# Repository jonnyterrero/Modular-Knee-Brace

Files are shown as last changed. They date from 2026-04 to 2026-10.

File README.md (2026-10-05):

# Modular Knee Brace (MK-Brace)

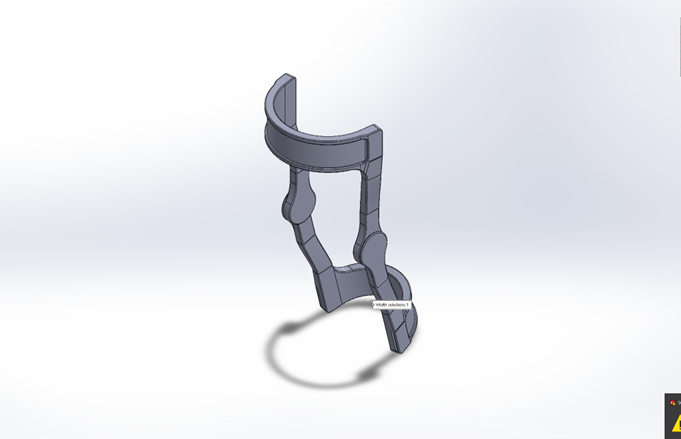
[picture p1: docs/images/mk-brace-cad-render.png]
CAD render of the modular knee brace frame (isometric view)


## Overview
The Modular Knee Brace (MK-Brace) is a lightweight, 3D-printed, parametric rehabilitation device designed to provide joint support, improve comfort, and enable biomechanical data collection.

This project focuses on developing a modular orthopedic system that bridges mechanical design, embedded systems, and rehabilitation engineering.

The current version is a **passive modular brace with planned sensor integration** for motion tracking, load monitoring, and usage analysis.

---

## Objectives

- Reduce bulk and weight compared to traditional braces
- Improve comfort and wearability
- Enable modular customization and repair
- Support a range of leg sizes through parametric CAD
- Provide a platform for biomechanical sensing and data collection
- Maintain low-cost, accessible manufacturing via 3D printing

---

## Key Features

### Mechanical Design
- Modular architecture with interchangeable components
- Mirrored hinge system for bilateral use
- Snap-fit connections with optional secondary fastening
- Parametric sizing for user-specific adjustments
- Designed for rapid prototyping via STL-based workflows

### Materials
- Primary: PLA / PETG (prototype), Nylon (future iterations)
- Structural upgrades: Carbon-fiber-reinforced materials (planned)
- Comfort interface: TPU / soft padding + Velcro straps

### Manufacturing
- Designed in SolidWorks; rebuilt as a parametric Fusion 360 model (2026)
- Exported as STL files (`cad/fusion/stl/`, millimetres)
- Fabricated via FDM 3D printing
- Post-processing includes support removal and adhesive reinforcement

---

## Fusion 360 Model

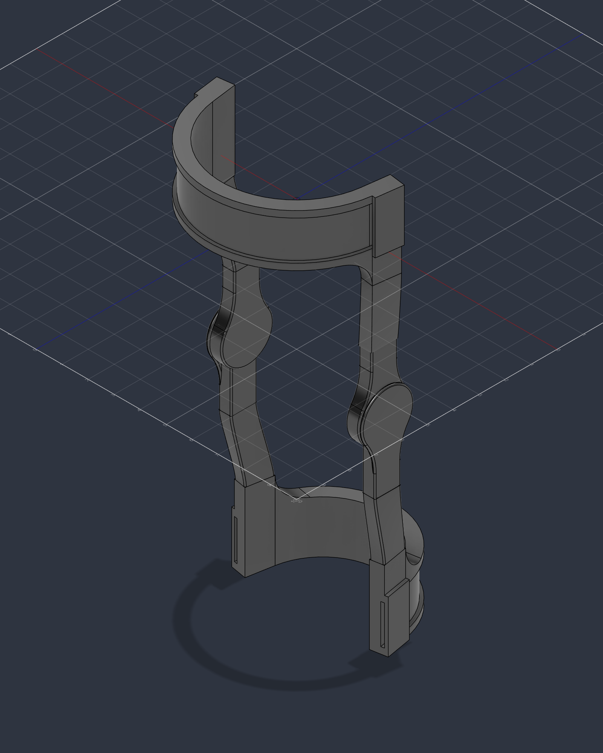
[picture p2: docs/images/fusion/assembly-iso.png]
Fusion 360 assembly of the MK-Brace


The brace was rebuilt in Fusion 360 from the final SolidWorks parts (October 2026):

- **Frames:** native and fully parametric. Thigh and calf fit, wrap angle, socket fit and strap geometry are named parameters.
- **Connectors and hinges:** exact copies of the original SolidWorks parts, positioned around the knee axis.
- **Verified fit** at every joint; corrections to the originals are documented in [`docs/fusion-rebuild.md`](docs/fusion-rebuild.md).

Files, parameters and build scripts: [`cad/fusion/`](cad/fusion/README.md). Current status and next steps: [`HANDOFF.md`](HANDOFF.md).

---

## System Architecture (Planned)

### Mechanical Subsystem
- Hinges (primary load-bearing)
- Connectors (modular joints)
- Upper and lower supports
- Adjustable fastening system

### Embedded System (Future Integration)
- Microcontroller: ESP32
- Sensors:
  - Magnetic rotary encoder (knee angle)
  - Dual IMUs (thigh + shin)
  - Pressure sensors (fit and load monitoring)
- Power: LiPo battery
- Communication: BLE / USB

---

## Use Case

The MK-Brace is designed for:
- Post-injury rehabilitation
- Mild-to-moderate knee instability
- Gait monitoring and movement tracking
- Long-duration wearable support

---

## Development Roadmap

### Phase 1 — Mechanical Prototype
- Finalize CAD geometry
- Print and assemble prototype
- Validate fit, comfort, and structural integrity

### Phase 2 — Instrumentation
- Integrate sensors into brace structure
- Develop mounting and enclosure solutions

### Phase 3 — Firmware
- Sensor acquisition and filtering
- Angle estimation and motion tracking
- Data logging and communication

### Phase 4 — Data & Analysis
- ROM tracking
- Usage analytics
- Gait pattern insights

### Phase 5 — Iteration & Optimization
- Material upgrades
- Custom PCB development
- Improved ergonomics and manufacturability

---

## Current Status
- Mechanical design: Fusion 360 rebuild complete (10-part parametric assembly, fit verified)
- Prototype fabrication: Print files ready in `cad/fusion/stl/`
- Embedded system: Next: sensors, battery and schematics (see `HANDOFF.md`)
- Software stack: Fusion API build and export scripts in `cad/fusion/scripts/`; firmware not started

---

## Repository Structure

| Path | Contents |
| --- | --- |
| `docs/` | Course write-up `EGN-3433C-Design-Project-Final.docx`; images in `images/`; dimensioned drawings and design sketches in `drawings/`; FEA report in `simulation/`; rebuild notes `fusion-rebuild.md`; session logs in `progress/` |
| `cad/` | Top-level release assembly: `finalkneeassem4.SLDASM` |
| `cad/fusion/` | Fusion 360 model: `.f3d` archive, STEP assembly, per-part STLs (mm) and Fusion API scripts |
| `cad/solidworks-final/` | Final SolidWorks parts, assemblies and drawings the Fusion model was rebuilt from |
| `HANDOFF.md`, `AGENTS.md`, `CLAUDE.md` | Current state and next steps; instructions for AI agents |
| `modular-knee-brace-package/` | Complete design hand-off: instruction PDF, SolidWorks assemblies and parts, STL print files, and simulation artifacts (`files/`, including `.CWR` and related solver files) |
| `resources/` | Pointers to external learning repos, [GrabCAD](https://grabcad.com/), and [SolidWorks Python tooling](https://github.com/Glutenberg/swtoolkit) (see `resources/README.md`) |

Large CAD, meshes, and simulation results are stored with **Git LFS**; clone with [Git LFS](https://git-lfs.com/) installed so pointers resolve to real files.

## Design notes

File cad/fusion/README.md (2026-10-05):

# Fusion 360 model

Parametric Fusion 360 rebuild of the MK-Brace (October 2026). The live design is **Modular Knee Brace** in the Fusion project **Knee brace Design**; the files here are exports of it plus the scripts that build it.

Fusion 360 assembly

## Files

| Path | What it is |
| --- | --- |
| `Modular-Knee-Brace.f3d` | Fusion archive with the full timeline, user parameters and all 10 parts (*File → Open → Open from my computer*) |
| `Modular-Knee-Brace.step` | Neutral STEP of the whole assembly in its assembled position |
| `stl/` | One binary STL per part, in **millimetres**, ready to slice |
| `scripts/` | Fusion API scripts that rebuild, measure and export the design |

### Parts and print quantities

| Part | STL | Qty | Source |
| --- | --- | --- | --- |
| Top Frame (thigh) | `top-frame.stl` | 1 | Native parametric (`build_frames`) |
| Bottom Frame (calf) | `bottom-frame.stl` | 1 | Native parametric (`build_frames`) |
| Upper Connector | `left-upper-connector.stl`, `right-upper-connector.stl` | 1 each | Original SolidWorks geometry |
| Lower Connector | `left-lower-connector.stl`, `right-lower-connector.stl` | 1 each | Original SolidWorks geometry |
| Inner Hinge | `left-inner-hinge.stl`, `right-inner-hinge.stl` | 1 each | Original SolidWorks geometry |
| Outer Hinge | `outer-hinge.stl` | **2** | Original SolidWorks geometry |

## Coordinates and units

- Model units are inches. Y is the leg axis (up), Z points to the front, X is lateral.
- The Top Frame is the assembly origin; the knee (hinge) axis is at (0, −6.0, −0.5) in.

## Frame parameters

Change them in *Modify → Change Parameters*; both frames, their sockets, gussets and strap paths follow.

| Parameter | Default | Meaning |
| --- | --- | --- |
| `top_frame_id` | 5.75 in | Top frame bore (thigh fit) |
| `bottom_frame_id` | 4.50 in | Bottom frame bore (calf fit) |
| `top_frame_half_angle` | 82.5° | Half the top frame's wrap |
| `bottom_frame_half_angle` | 80° | Half the bottom frame's wrap (matches the lower connectors' 10° tabs) |
| `frame_height` | 2.00 in | Band height |
| `frame_wall` | 0.50 in | Band thickness |
| `block_length`, `block_drop` | 1.00 in, 1.00 in | End block length; how far it drops toward the knee (also the gusset radius) |
| `tab_width`, `tab_thickness`, `tab_length` | 0.75, 0.25, 1.00 in | Connector tab |
| `fit_clearance` | 0.01 in | Per side, tab to socket |
| `socket_flare_depth` | 0.319 in | Flared socket mouth that seats the tab's R0.5 root |
| `strap_recess_height`, `strap_recess_depth` | 1.50 in, 0.125 in | Strap recess and strap slot |
| `lip_thickness` | 0.125 in | Strap bridge over each end-block slot |

The connectors and hinges are exact copies of the SolidWorks parts, so they do **not** follow these parameters (see [`docs/fusion-rebuild.md`](../../docs/fusion-rebuild.md)).

## Scripts

| Script | Does |
| --- | --- |
| `build_frames` | Creates the parameters and both parametric frames in the active design |
| `place_original_parts` | Copies the original connectors and hinges from *Knee brace Design / SolidWorks originals* and places them around the knee |
| `measure_part` | Prints size, volume, cylinder diameters and planar-face offsets of every body |
| `export_brace` | Writes the `.f3d`, `.step`, `stl/` and the `docs/images/fusion/` renders back into this repo |

Run one from Fusion: *Utilities → Add-Ins → Scripts and Add-Ins → + (Script) → select its folder → Run*.

Rebuild from scratch: new design → `build_frames` → `place_original_parts`. On 2026-10-04 this reproduced the saved design exactly (all 10 parts, volume and bounding box).

From Claude Code with the Fusion MCP connected, run a repo script by loading the file, so the committed code is what runs:

```python
import importlib.util

def run(_context: str):
    path = r'<repo>\cad\fusion\scripts\build_frames\build_frames.py'
    spec = importlib.util.spec_from_file_location('build_frames', path)
    module = importlib.util.module_from_spec(spec)
    spec.loader.exec_module(module)
    module.run('')
```

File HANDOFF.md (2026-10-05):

# Handoff — where the MK-Brace work stands

_Last updated 2026-10-04 by Claude Code (Opus 5.5). Full session log: [`docs/progress/2026-10-04-fusion-rebuild.md`](docs/progress/2026-10-04-fusion-rebuild.md)._

Read this first when picking the project back up, and update it at the end of every session.

## Current state

- **Phase 1 (mechanical): Fusion rebuild done.** The brace is a 10-part Fusion 360 assembly: two parametric frames plus exact copies of the original connectors and hinges, with fit checked at every joint.
- **Fusion cloud:** project **Knee brace Design** holds the design **Modular Knee Brace** (v2) and the folder **SolidWorks originals** (the 9 converted reference parts). Save new Fusion work in this project, never in *Default Project*.
- **Repo:** exports and scripts in [`cad/fusion/`](cad/fusion/README.md); engineering notes in [`docs/fusion-rebuild.md`](docs/fusion-rebuild.md); the reference SolidWorks set in [`cad/solidworks-final/`](cad/solidworks-final/); drawings in [`docs/drawings/`](docs/drawings/).
- **Print-ready:** `cad/fusion/stl/` (millimetres). Print the Outer Hinge twice.

## Next up (week of 2026-10-05): electronics

The README's Phase 2/3 plan: ESP32, a magnetic rotary encoder at the hinge (knee angle), dual IMUs (thigh + shin), pressure sensors (fit and load), a LiPo battery, BLE/USB.

1. Choose parts and write a power budget (target runtime → battery capacity).
2. Draw the schematics in KiCad (an MCP server is configured on the dev machine) or Fusion Electronics, under a new `electronics/` folder.
3. Design the mounts in Fusion. The report puts add-ons at the hinges first, so start with the encoder on the hinge axis and an enclosure for the MCU and battery.
4. Update this file, add a `docs/progress/` entry, and commit to `main`.

Open questions:

- Is electrical-stimulation (e-stim) therapy in scope? The report mentions an e-stim battery pack. Anything patient-connected is safety-critical: keep it a separate, isolated module and decide before designing the power system.
- Target runtime per charge, and where the battery and MCU should sit (thigh frame or hinge).
- Material for the first printed prototype (README: PLA/PETG now, nylon or carbon fibre later).

## Resume on the desktop

1. Pull this repo (Git LFS required) and open it in Claude Code.
2. Start Fusion. Its MCP server must be on port **47182** (Preferences → General → API); [`AGENTS.md`](AGENTS.md#fusion-360-via-mcp) explains why.
3. Open **Knee brace Design / Modular Knee Brace** and confirm the Fusion tools respond.

## Known issues

- The frames lack the originals' small edge rounds and end-block draft (cosmetic).
- Connectors and hinges don't follow the frame parameters (copied geometry).
- About 0.003 in press fit on one side of each hinge seat, inherited from the originals.

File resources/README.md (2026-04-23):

# Resources

Curated external links for SolidWorks learning, example files, community CAD, and API automation. These are not part of the MK-Brace project; they are reference material for contributors and future design work.

## Training & exercise repositories

| Resource | Link | Notes |
| --- | --- | --- |
| *SOLIDWORKS 2016 Essential Training* (Tertiary Infotech) — exercise files | [tertiarycourses/SolidworksTraining](https://github.com/tertiarycourses/SolidworksTraining) | Official course materials for a structured essentials curriculum; [course outline](https://www.tertiarycourses.com.sg/solidworks-2016-essential-training.html) is listed in that repo. |
| *Learn SOLIDWORKS* (second edition, Packt) — chapter project files | [PacktPublishing/Learn-SOLIDWORKS-Second-Edition](https://github.com/PacktPublishing/Learn-SOLIDWORKS-Second-Edition) | Book companion assets organized by chapter; see the book README for the intended software and chapter mapping. |

## SolidWorks + Python (API automation)

| Resource | Link | Notes |
| --- | --- | --- |
| SW ToolKit | [Glutenberg/swtoolkit](https://github.com/Glutenberg/swtoolkit) | Python toolkit to script SolidWorks (batch exports, build automation, etc.). **Requires** a local SolidWorks install and a Windows environment suitable for the COM API. |

## Community CAD

| Resource | Link | Notes |
| --- | --- | --- |
| GrabCAD | [grabcad.com](https://grabcad.com/) | Public library of user-uploaded models; useful for reference geometry, fastener/standard parts, and design inspiration. Check each model’s **license and terms of use** before reusing. |

---

## Disclaimer

Repository contents and licenses are defined by their respective owners. Verify compatibility with your **SolidWorks version** before opening third-party files.

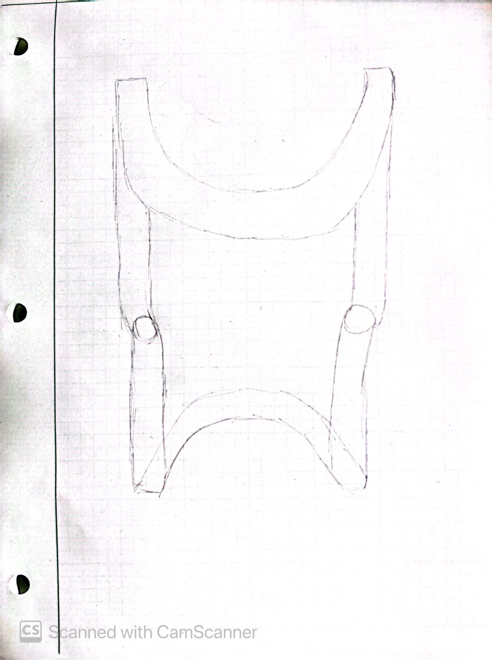
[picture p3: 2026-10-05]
docs/drawings/sketch-concept.jpg

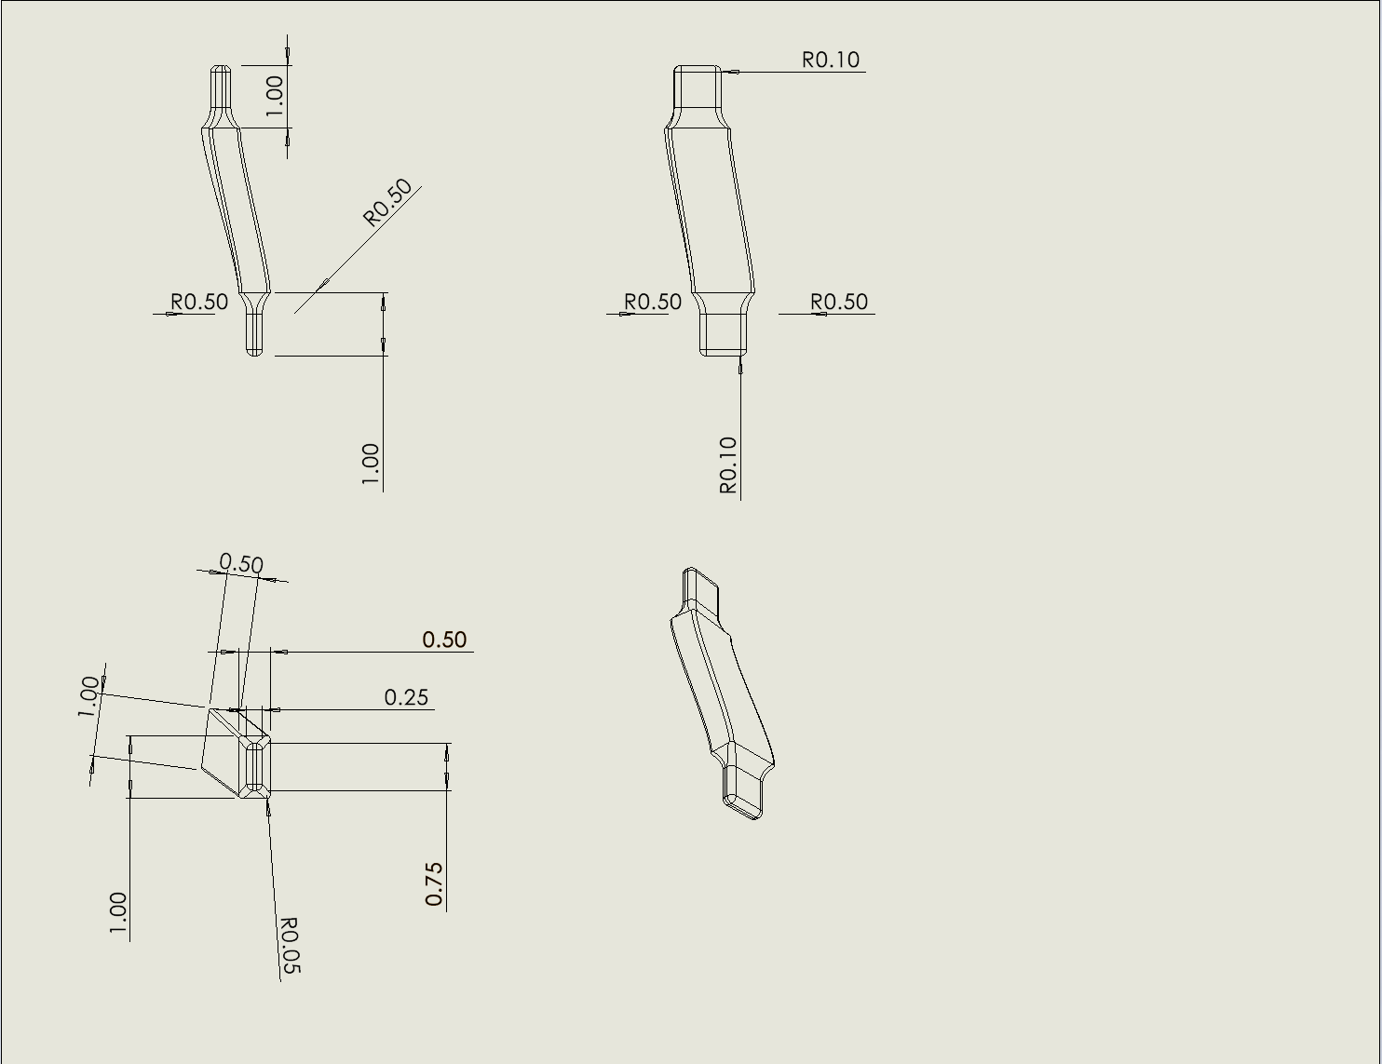
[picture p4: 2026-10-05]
docs/drawings/drawing-3-upper-connector.png

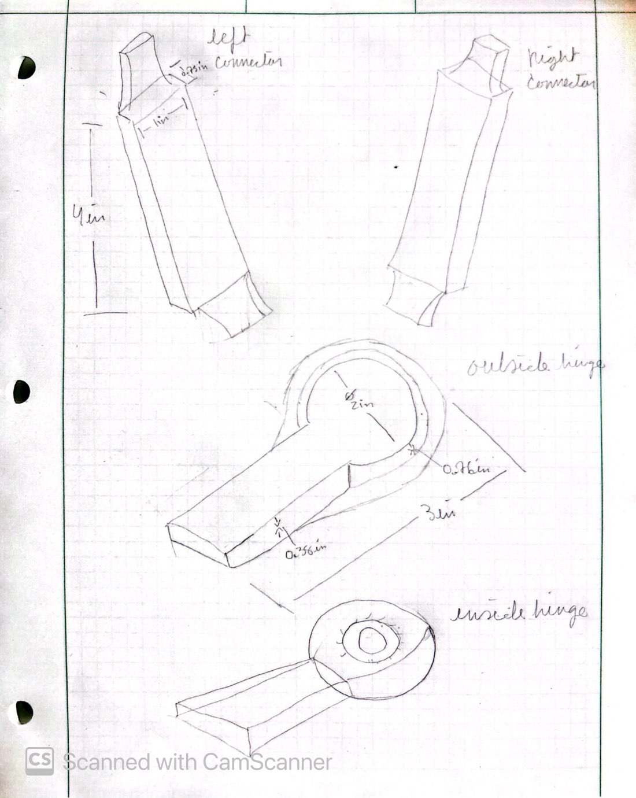
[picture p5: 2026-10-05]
docs/drawings/sketch-connectors-and-hinges.jpg

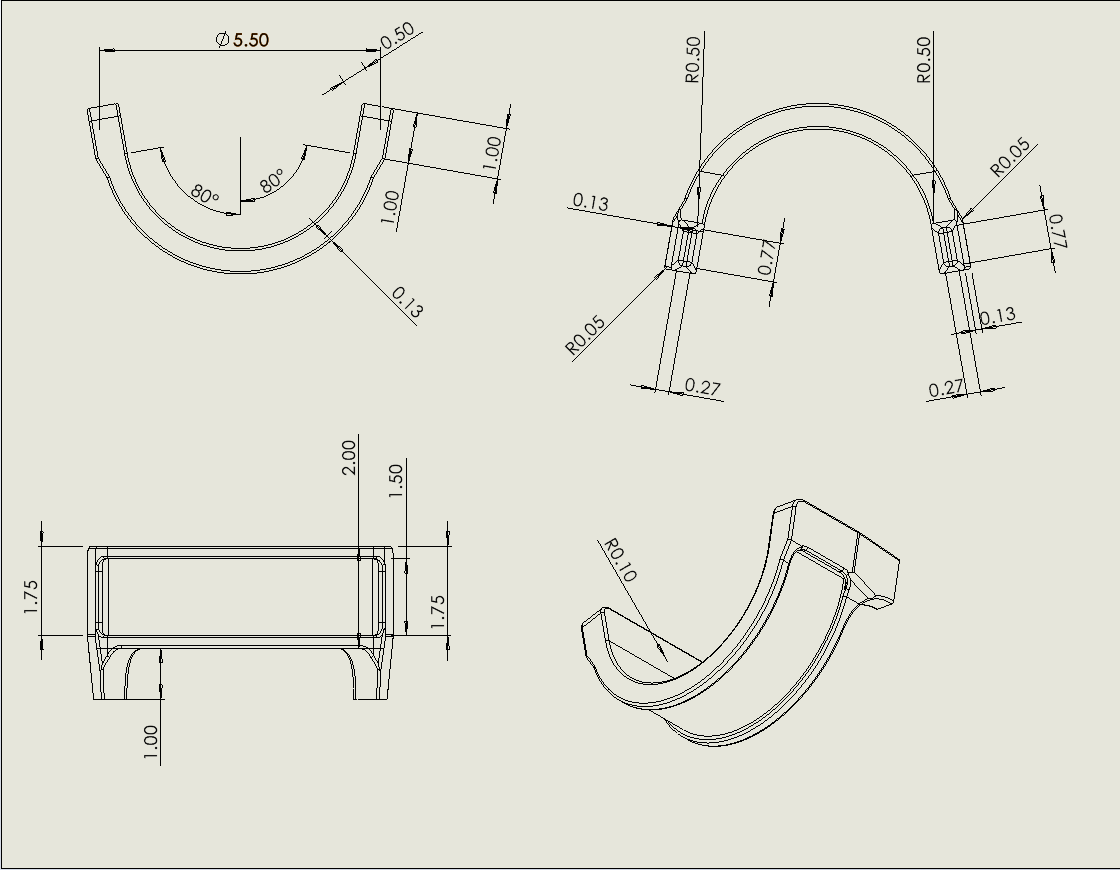
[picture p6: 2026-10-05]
docs/drawings/drawing-2-bottom-frame.png

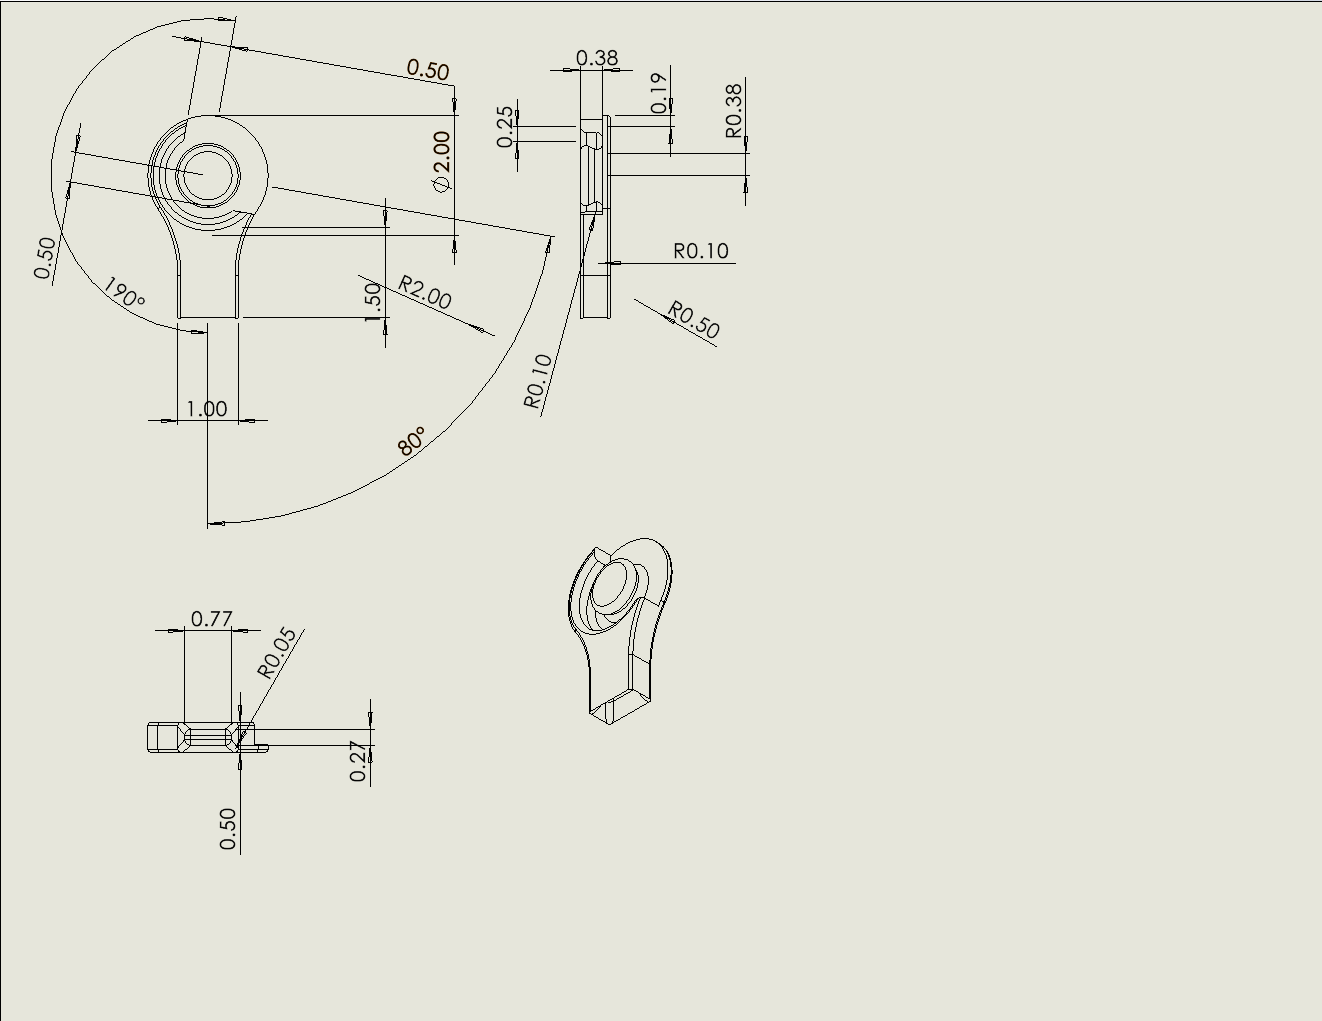
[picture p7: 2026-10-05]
docs/drawings/drawing-6-inner-hinge.png

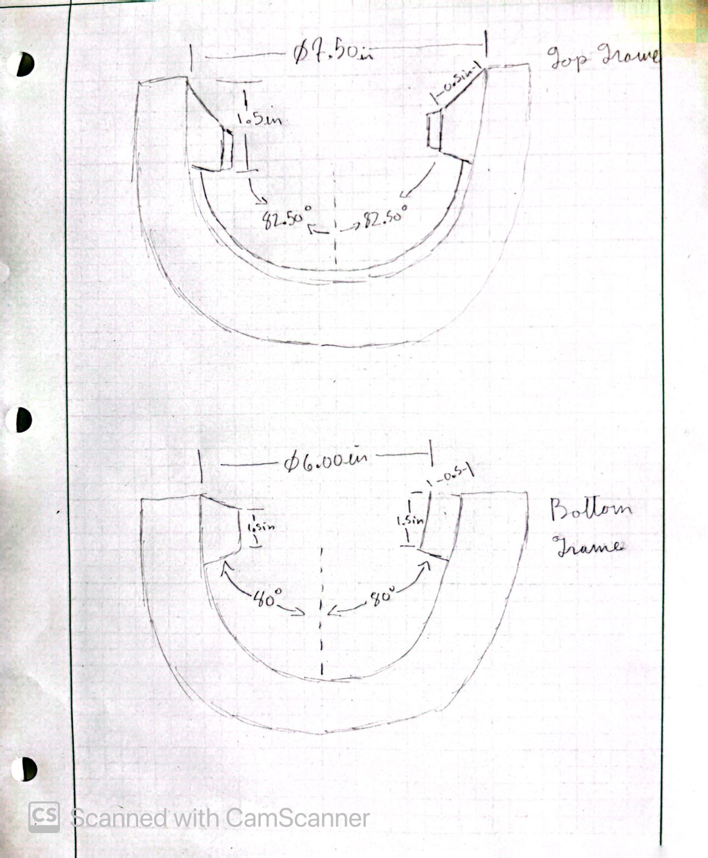
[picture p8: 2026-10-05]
docs/drawings/sketch-frames.jpg

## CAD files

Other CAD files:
cad/finalkneeassem4.SLDASM
cad/solidworks-final/Final_Final_Assembly.SLDASM
modular-knee-brace-package/files/Left_Hinge.SLDASM
cad/solidworks-final/hingeassembly.SLDASM
modular-knee-brace-package/files/Assem1.SLDASM
modular-knee-brace-package/files/FINAL_BRACE_ASSEMBLY.SLDASM
modular-knee-brace-package/files/Right_Hinge.SLDASM
modular-knee-brace-package/files/Assem2.SLDASM
cad/fusion/Modular-Knee-Brace.step
cad/fusion/stl/right-upper-connector.stl
cad/solidworks-final/Hinge_Outerfinal.SLDPRT
modular-knee-brace-package/files/Left_Lower_Connectorfinal.SLDPRT
cad/fusion/stl/left-upper-connector.stl
cad/solidworks-final/Left_Hinge_Innerfinal.SLDPRT
modular-knee-brace-package/files/Left_Lower_Connector.STL
cad/fusion/stl/right-inner-hinge.stl
cad/solidworks-final/Right_Upper_Connectorfinal.SLDPRT
modular-knee-brace-package/files/Lower.SLDPRT
cad/fusion/Modular-Knee-Brace.f3d
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

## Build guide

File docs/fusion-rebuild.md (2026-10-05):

# Fusion 360 rebuild — engineering notes

How the SolidWorks MK-Brace became the parametric Fusion model in [`cad/fusion/`](../cad/fusion/README.md), what was measured, and what was corrected. Session log: [`progress/2026-10-04-fusion-rebuild.md`](progress/2026-10-04-fusion-rebuild.md).

## Source of truth

The rebuild follows the final SolidWorks set in [`cad/solidworks-final/`](../cad/solidworks-final/). Those `…final` parts were saved on 2025-05-02, the day the final report was saved, after every iteration in the course working folder (`pt2`, `pt3`, `Mirror…`). They differ from the parts in `modular-knee-brace-package/`.

The parts were uploaded to Fusion (project *Knee brace Design*, folder *SolidWorks originals*), converted, and measured face by face with `measure_part`.

## Measured geometry

### Frames (one design, two sizes)

| | Top Frame (thigh) | Bottom Frame (calf) |
| --- | --- | --- |
| Bore / outside diameter | 5.75 / 6.75 in | 4.50 / 5.50 in |
| Wrap (2 × half-angle) | 165° | 160° (see corrections) |
| Band height × wall | 2.00 × 0.50 in | 2.00 × 0.50 in |
| End blocks | 1.00 in tangent extension; drop 1.00 in toward the knee | same |
| Socket | 0.77 × 0.27 in, 1.01 in deep, R0.5 flared mouth over 0.319 in | same |
| Strap path | 1.50 × 0.125 in recess on the band, continuing through a slot in each end block under a 0.125 in bridge | same |
| Gusset | R1.00 between each end block and the band underside | same |

### Connectors

- Body 1.00 × 0.50 in; tabs 0.75 × 0.25 in. Each tab is 1.00 in from tip to body, including a 0.331 in R0.5 flared root.
- Upper connector 4.634 in long; lower connector 4.500 in.
- Each connector is lofted: the frame-end tab is rotated to match its frame socket (7.5° upper, 10° lower) while the hinge-end tab is square to the hinge. The twist runs in opposite directions on the two sides of the leg, which is why there are separate Left and Right parts.

### Hinge (snap-fit pivot)

- **Inner Hinge** (Left/Right): Ø2.00 × 0.50 in hub with a Ø1.625 × 0.375 in recess, a central mushroom snap boss, and a partial rim that acts as a rotation stop. Arm length 2.366 in from the hub centre.
- **Outer Hinge** (one part, used on both sides): Ø1.60 in spigot that seats in the Inner Hinge's recess, a Ø2.00 × 0.125 in cap, and a snap hole for the boss. Arm length 2.500 in.
- Every arm ends in the same 0.77 × 0.27 × 1.01 in socket with a flared mouth.

## Assembly layout

- Y is the leg axis (up), Z the front, X lateral. The Top Frame is the origin; the knee axis is at (0, −6.0, −0.5) in.
- The thigh frame's axis sits 0.5 in forward of the hinge axis and the calf frame's 0.5 in behind it, exactly where the original connector files place them.
- Load path on each side: Top Frame → Upper Connector → Inner Hinge ⟲ Outer Hinge → Lower Connector → Bottom Frame. Tabs seat fully (1.00 in), leaving 0.01 in at each socket floor.
- The Bottom Frame is the frame design flipped about X, so its band wraps the back of the calf and its sockets face the knee.

## Fit check

- Frame ↔ connector joints (all four): zero overlap by solid intersection.
- Hinge joints: tabs clear their sockets by at least 0.003 in along the straight section and stop 0.01 in short of the socket floor.
- The original connectors' tab spacing at the hinge is 0.014 in off the hinge stack. The hinges are placed to split it, leaving about 0.003 in press fit on one side of each flared seat, which is below FDM tolerance.

## Corrections to the originals

| Issue | In the originals | In the rebuild |
| --- | --- | --- |
| Frame diameters on the drawings | Ø6.75 / Ø5.50 read like bores | They are outside diameters; the bores are 5.75 / 4.50 in |
| Bottom Frame wrap | `Lower.SLDPRT` wraps 82.5° (7.5° sockets) while the lower connectors' tabs are angled 10° (Drawing 2's 80°); with 0.01 in clearance that 2.5° mismatch jams | Built at 80° so the connectors seat |
| Hinge tab spacing | 0.014 in mismatch between connectors and hinge stack | Split; see the fit check |

## Not yet reproduced

- R0.05–R0.10 edge rounds, the draft on each end block's lower outer face, and R0.25 corners at the strap openings.
- The connectors and hinges are exact copies (base features), so they do not follow the frame parameters. Rebuild them parametrically before a large refit.
- No materials, appearances or motion joints yet.

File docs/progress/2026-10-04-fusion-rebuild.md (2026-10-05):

# 2026-10-02 to 2026-10-04 — SolidWorks to Fusion 360 rebuild

Claude Code (Opus 5.5). The work started in a session in the `workflows-and-automations` repo and was ported here.

## 1. Fixed the Fusion ↔ Claude connection

The Autodesk Fusion connector kept failing ("Version negotiation failed … server/discover probe", `ECONNRESET`). Root cause: MATLAB's MathWorks Service Host serves HTTPS on `127.0.0.1:27182`, the same default port as Fusion's MCP server, and starts at every login. Fusion moved to port 47182 and every client now points there (details in `AGENTS.md`). Verified across a full restart.

## 2. Recovered the real geometry

- Extracted the text and 23 figures from the final report; the six dimensioned drawings are in `docs/drawings/`.
- Uploaded the final SolidWorks parts to Fusion (*Knee brace Design / SolidWorks originals*) and measured every face.
- Findings: the drawing diameters are outside diameters (bores 5.75 and 4.50 in); the bands are 2.00 in tall; the sockets flare to seat the connectors' R0.5 tab roots; the connectors are lofted with a 7.5° / 10° twist; the hinge is a recess-and-spigot snap-fit pivot.

## 3. Built the model

- Native parametric frames (`build_frames`): band, end blocks, sockets with flared mouths, strap recess, R1.00 gussets, strap bridges and slots, all driven by user parameters.
- Exact copies of the original connectors and hinges (`place_original_parts`), positioned around the knee axis.
- Fit verified at every joint (see `docs/fusion-rebuild.md`).
- Decisions: the Bottom Frame wraps 80° because the original `Lower.SLDPRT` (82.5°) would jam the 10° lower connectors; the 0.014 in hinge tab-spacing mismatch is split between both seats; connectors and hinges stay as copies for now.

## 4. Saved and exported

- Fusion: *Knee brace Design / Modular Knee Brace* v2, with the converted originals moved into the same project.
- Repo: `cad/fusion/` (`.f3d`, `.step`, 9 STLs in mm, scripts), `cad/solidworks-final/`, renders, drawings and these notes.
- The repo scripts rebuilt the saved design exactly in a fresh document (all 10 parts, volume and bounding box).

## Next

Electronics; see `HANDOFF.md`.

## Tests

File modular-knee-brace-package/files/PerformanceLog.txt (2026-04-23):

Number of Contacts: 177
Number of contact data: 11806

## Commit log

2026-04-23 Add design package, course doc, and MK-Brace README
    Includes SolidWorks hand-off, STLs, simulation artifacts (Git LFS), final assembly, and EGN 3433C report. README documents objectives, roadmap, and repo layout.
    Made-with: Cursor
    [Assem1.SLDASM, Assem2.SLDASM, FINAL_BRACE_ASSEMBLY.SLDASM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]
2026-04-23 Add resources folder with external SolidWorks and CAD links
    Lists tertiarycourses/SolidworksTraining, Packt Learn SOLIDWORKS, Glutenberg/swtoolkit, and GrabCAD. Root README table updated.
    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
2026-04-23 Add CAD render image to README
2026-10-05 Add Fusion 360 rebuild, verified build scripts, and session handoff
    Port the SolidWorks-to-Fusion rebuild into the project repo so the
    model, the code that builds it, and the reasoning behind it live here:
    - cad/fusion: Fusion archive, STEP assembly, per-part STLs (mm), and
    Fusion API scripts that rebuild the saved design exactly
    - cad/solidworks-final: the final SolidWorks parts, assemblies and
    drawings the rebuild was measured from
    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
    [Final_Final_Assembly.SLDASM, Hinge_Outerdrawing.SLDDRW, Hinge_Outerfinal.SLDPRT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]
2026-10-20 Add Phase 2 electronics plan: parts, pin map, power budget
    Sensing-only build (no e-stim), ~12 h runtime, MCU + encoder + shin IMU
    at the lateral hinge, 1000 mAh protected LiPo on the thigh frame.
    Records the hinge-axis measurements that drive the encoder mount.
2026-10-20 Add Phase 2 sensing schematic (KiCad 10)
    One-sheet schematic for the hinge board, thigh harness end and calf FSRs:
    XIAO ESP32-S3, AS5600 on the hinge axis, 2x LSM6DSOX (0x6A/0x6B),
    4x FSR dividers gated by FSR_EN, switched VBAT with a sense divider.
    Project symbols for parts missing from KiCad's stock library.
    ERC: 0 errors; netlist checked against the design. PDF exported.
2026-10-20 Schematic rev B (WIP): power path, AS5600 DIR, FSR ADC range
    From an external design review, checked against the AS5600 and ESP32-S3
    datasheets:
    - SW1 and a 0.5 A PTC (F1) moved to the cell on the thigh side, so the
    harness carries no battery voltage when off and is short-protected
    - AS5600 DIR tied to GND (must not float); D7 freed
    - 1.5k series resistors on each FSR line keep the ADC input <= 2.87 V
    (ESP32-S3 12 dB range is 0-2.9 V) and limit harness fault current
    ERC 0 errors; netlist re-checked. Remaining rev B items in HANDOFF.md.
2026-11-02 Redesign hinges, connectors and frame sockets for FDM printing
    The original hinges could not be printed and assembled: about 11% hoop
    stretch through a solid snap ring, and near-zero gaps at three faces.
    - Hinges: cup and spigot with 0.41 mm running clearance, a six-finger
    slit snap post, a 45 deg barb seat and an open bore in the cap
    - Connectors: prismatic profiles printed on edge, same part both sides
    - Frames: 180 deg wrap squares the sockets and removes the connector
    twist; flares replaced by a flat shoulder
    - New build_print_parts script; export strips Fusion name suffixes
    Checked in Fusion: no overlaps at rest, free from -1 to 115 deg. Not yet
    sliced or printed. Fusion design sa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
2026-11-02 Finish schematic rev B: XIAO footprint and pads, battery plug, checklist
    - Correct XIAO battery pads to 23 (VBAT) and 24 (GND) and use Seeed's
    footprint (CC BY-SA 4.0, Seeed-Studio/OPL_Kicad_Library)
    - Add J4 battery plug on the thigh side
    - Use KiCad 10 stock symbols; ERC now 0 errors, 6 intended warnings
    - Add title block, part numbers and the design review checklist
    - Flag the slow onboard charger as an open decision
    LSM6DSOX pinout is still checked only against the sister LSM6DSO.
2026-11-02 Decide off-brace charging: unplug the cell at J4
    The XIAO's onboard charger would take 10-20+ hours on 1000 mAh. The cell
    now charges off the brace with a 500 mA single-cell charger, so it can't
    charge while worn. Adds the charger to the BOM and a polarity warning,
    since JST-PH battery wiring isn't standardized.
2026-11-02 Split the sensing schematic into hinge and thigh board projects
    The full build is sensing only, so it comes down to two PCBs, and KiCad
    has one PCB per project.
    - hinge-board and thigh-board projects sharing electronics/kicad/lib
    - Add J5 for the thigh FSRs and a footprint for SW1
    - Mark the battery and FSRs as off-board
    - Add check_harness.py, since KiCad can't link J1 and J3 across projects
    Combined netlist matches the single sheet apart from J5. ERC: 0 errors,
    3 intended warnings per board. No layout yet.
2026-11-02 Choose the battery, fuse, switch and charger
    - Cell: Adafruit 258, 1200 mAh with PCM, about 22 h at the design load
    - Fuse: Littelfuse 1206L050YR, 0.5 A hold, 1 A trip
    - Switch: C&K PCM12SMTR, 300 mA at 6 VDC
    - Charger: Adafruit 4410, jumpered for 500 mA; same vendor as the cell
    ESP32-S3 BLE TX peaks at 335 mA at 21 dBm, over the switch rating, so
    firmware must limit BLE TX to 9 dBm or less. Noted on both schematics.
    Nets unchanged; ERC 0 errors. Peak current is calculated, not measured.
2026-11-11 Add session notes for the 2026-10-20 to 11-02 Claude Code session
    That session ran from the integrations&automations worktree, so its
    context lived outside this repo. docs/sessions/ brings it here: a
    timeline with commits, decisions and who made them, Fusion and KiCad
    tooling lessons, and open items. Linked from HANDOFF.md and AGENTS.md.
2026-11-13 Add a print package: STLs on their print faces plus a lab sheet
    The Fusion export leaves parts in model orientation, so a lab slicing
    them as-is could print the hinges on edge or the frames tallest-up.
    cad/fusion/print/ has each part on its print face at Z=0 and a sheet
    with quantities, settings and a hinge-pair-first test plan.
    orient_for_print.py builds the package without Fusion and checks every
    mesh: all 7 are closed and outward-facing, and bed contact and overhang
    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
